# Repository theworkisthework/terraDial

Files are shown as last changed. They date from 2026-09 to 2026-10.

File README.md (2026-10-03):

# terraDial

Standalone control panel for the **terraPen** pen plotter, running on an
Elecrow CrowPanel 1.28" round display — a 240×240 touchscreen with a rotary
knob. It talks to [FluidNC](http://wiki.fluidnc.com/) over a WebSocket, so
the plotter can be driven from the bench without a laptop or phone.

Parent project: [terraForge](https://github.com/theworkisthework/terraForge)
(the desktop app this panel descends from — and the source of its colour
palette). Sibling: terraPixel (the rail lighting controller this panel can
also drive).

## What it does

- **Jog** X/Y/Z by knob, with selectable step sizes (0.1 / 1 / 10 / 100mm on
  X and Y; Z is capped at 1mm, being only a pen lift) and a per-axis *Set zero*
- **Run G-code** straight off the plotter's SD card, with live progress,
  elapsed time and an estimate of the time remaining — including for jobs
  started from terraForge or the web UI rather than the panel
- **Pen up/down**, **homing** (with a clear-the-bed confirmation), **E-Stop**
  and **alarm clear**, the last showing FluidNC's own reason for the alarm
- **Park for photo** — one dial item that lifts the pen, homes, then runs the
  gantry out to the far end of Y so the finished plot can be photographed
  unobstructed. Sequenced against the status stream rather than fired blind,
  since G-code sent mid-homing is rejected
- **Rail lighting** control via terraPixel — brightness, film mode, comet width
- **On-device Wi-Fi setup**: scan for networks, pick one, type the password
- **Machine status** shown on the panel's 5-LED ring, readable across the room
  — a jog chases a pixel the way you turned the knob, a plot breathes the
  whole ring slowly, and both dim with the screen when the panel sleeps
- **Sleep mode** so the panel isn't glowing at you through a multi-hour plot,
  with the terraPen mark shown while idle beforehand
- **About screen** carrying the project identity and QR links to the site,
  source and Discord — a 240px dial is no place to read a URL

## Screens

> These are **vector illustrations, not photographs.** They're generated by
> [`tools/gen_screens.py`](tools/gen_screens.py) from the real layout values —
> palette hex, ring radii, arc angles, hub and font sizes — so proportions and
> colours match the firmware, and icons are the same Lucide glyphs the
> firmware draws, but the panel's actual anti-aliasing isn't reproduced. A
> page taller than the round face is drawn once per screenful, scrolled.

### Main menu

The home dial and the screens it opens, in dial order.

| | | |
|:--:|:--:|:--:|
| <br>**Home** — 8 destinations, E‑Stop always red | <br>**Home XY** — clear‑the‑bed gate | <br>**Jog** — axis, position, per‑axis zero |
| <br>**Pen** — up / down | <br>**Jobs** — SD files on an open arc | <br>**E‑Stop** — feed hold + soft reset |
| <br>**Lights** — terraPixel rail control | | |

### Settings

The Settings sub‑menu, then each of its pages.

| | | |
|:--:|:--:|:--:|
| <br>**Settings sub‑menu** — Wi‑Fi, Machine, Display, About | <br>**Wi‑Fi** — network, password, connect | <br>**Wi‑Fi: network picker** — tap the SSID to scan |
| <br>**Machine: hosts** — FluidNC host / IP | <br>**Machine: pen up / down commands** — swap, reset to defaults | <br>**Machine: terraPixel** — lights host / IP |
| <br>**Display: screen** — brightness, idle logo, menu rotation | <br>**Display: sleep** — sleep timeout, ring sleep brightness | <br>**About** — identity, QR links, diagnostics |

### Pop-up screens

Not in any menu: these open by themselves when they're needed.

| | | |
|:--:|:--:|:--:|
| <br>**Radial keyboard** — opens when you tap a text field | <br>**Idle** — the mark, before sleep | <br>**Job progress** — opens when a job starts |
| <br>**Alarm clear** — appears on alarm | | |

## Hardware

| | |
|---|---|
| Board | Elecrow CrowPanel 1.28" Rotary (ESP32-S3R8, 16MB flash, 8MB PSRAM) |
| Display | GC9A01 240×240 round IPS, SPI |
| Touch | CST816D capacitive, I²C |
| Input | EC11-style rotary encoder with push switch |
| LEDs | 5× WS2812 ring around the bezel |

Pin assignments are in [`include/pins.h`](include/pins.h), confirmed against
Elecrow's factory example for this exact board rather than guessed.

### Power

It's a **USB-powered device** — a single USB-A lead carries both power and,
when you want it, the serial console and firmware flashing. There's no barrel
jack and no separate supply to find.

That also means it runs happily off a **USB battery pack**, which is handy for
a plotter that isn't parked next to a socket, or for filming without a cable
in shot. Two things worth knowing if you do:

- Many power banks cut out when they stop seeing meaningful current draw.
  This panel is a modest load to begin with, and screen sleep drops it further
  by switching the backlight off entirely — so a bank with an aggressive
  auto-shutoff may power down mid-plot. Banks with a "low-current" or
  "trickle" mode avoid this; otherwise turn sleep off (Settings → Display)
  when running from one.
- The bezel LED ring draws on the same supply, so a high ring brightness
  costs battery life directly. It's on the Lights screen if you want it down.

Enclosure files (`dial case.stl`, `frame mount.stl`, `backplate.dxf`) are in
the repo root.

## Installing and updating

Neither of these needs a toolchain, a checkout, or anything installed on the
computer. The Building section below is for changing the firmware, not for
running it.

### First install — the web installer

<https://theworkisthework.github.io/terraDial/>

Plug the panel into a computer with a USB-A **data** cable, open that page in
Chrome or Edge on the desktop, and click *Connect and install*. It talks to the
panel over Web Serial and writes the whole chip — bootloader, partition table
and app — so it also works on a board that has never been flashed, and on one
that has been flashed with something broken.

Safari, Firefox and every mobile browser lack Web Serial, so the page tells
them so rather than failing halfway.

Released builds ship with **no Wi-Fi credentials baked in** — the first boot
comes up unconnected, and you pick a network on the panel (Settings → Wi-Fi →
scan). That's the flow a stranger's board has to use anyway, so it's the one
that gets tested.

### After that — over Wi-Fi, from the panel

**Settings → About → Check for updates.**

The panel asks GitHub for the latest release, compares it against the version
it's running, and offers to install it. It downloads into the spare app slot
and reboots into it, so a failed or interrupted download leaves the working
firmware exactly where it was — there's no window where the panel is holding
half a firmware.

Two deliberate limits:

- **It refuses while the machine is busy.** The download blocks the same task
  that pumps FluidNC's WebSocket, for a minute or more, and the reboot at the
  end drops the connection outright. Mid-plot is the worst possible moment for
  both, so it says "Machine busy" and does nothing.
- **A dev build is always offered the release.** A build from a working copy
  carries the version `dev`, which has no place in the ordering — see
  `include/version.h`. If you're testing local firmware, don't press the button.

The About card shows the running version at the top, which is the thing worth
quoting in a bug report.

### Cutting a release

Tag it and push the tag; [`.github/workflows/release.yml`](.github/workflows/release.yml)
does the rest.

```bash
git tag v0.1.0
git push origin v0.1.0
```

That builds the firmware with the tag stamped in, attaches two images to the
GitHub Release, and redeploys the installer page:

| Asset | What it is |
|---|---|
| `terradial-ota.bin` | The app image. What the panel downloads for itself — the name is fixed, and `OTA_ASSET_NAME` in [`src/net/ota_updater.h`](src/net/ota_updater.h) has to keep matching it |
| `terradial-factory.bin` | Bootloader + partitions + app, merged for flashing at `0x0`. What the web installer writes |

Publishing the installer page is a second workflow,
[`pages.yml`](.github/workflows/pages.yml), which the first triggers on
success. That split isn't tidiness: the `github-pages` environment only
accepts deployments from the default branch, and a release workflow runs from
a tag — v0.1.0 failed exactly that way. A `workflow_run` trigger is evaluated
in the default branch's context whatever ref set it off, so it passes the rule
without anyone having to loosen a protection setting that lives nowhere in the
repo.

It downloads the factory image from the release it just made and serves it
from the Pages origin rather than linking to github.com — Web Serial fetches
the image with JS, and a cross-origin fetch the browser declines fails
quietly, which is a miserable thing to debug from a report that only says
"the button doesn't work".

**One-time repo setup:** Settings → Pages → Source must be set to *GitHub
Actions*, or the workflow builds everything and has nowhere to publish it.

### Test builds nobody else gets

A tag with a hyphen in it — `v0.2.0-rc1` — publishes as a GitHub
*prerelease*. It gets a release page and downloadable binaries like any
other, but no panel is offered it and the installer page ignores it: both
ask for `releases/latest`, and that endpoint skips prereleases.

That's also the only safe way to use a suffix. `versionRank()` in the
updater stops at the first non-digit, so `0.2.0-rc1` ranks *identically* to
`0.2.0` — two different builds it cannot tell apart. Keeping suffixed tags
out of `latest` means it never has to.

### Versions can only go forwards

The updater offers a release only when it ranks strictly higher than the
running build, and there is no downgrade path in the UI. So a bad release is
retired by tagging a **higher** number — never by deleting the release,
moving the tag, or re-uploading under the same one. None of those reach a
panel that has already updated.

## Building

Built with [PlatformIO](https://platformio.org/).

```bash
# 1. Build and flash
pio run -t upload

# 2. Watch the logs
pio device monitor
```

By default no credentials are compiled in: the panel boots unconfigured and
you pick a network on-device (Settings > Wi-Fi > scan). To bake in default
credentials or hostnames instead, copy `include/secrets.h.example` to
`include/secrets.h` (gitignored) and define whichever values you want to
override. They're only *defaults* either way: seeded into NVS on first boot,
after which the Settings screen can change networks without a reflash.

A local build reports its version as `dev` unless HEAD is exactly on a tag —
[`tools/version.py`](tools/version.py) only treats an exact tag as a release,
because a commit that merely descends from `v0.2.0` is newer than `v0.2.0`, and
stamping it as that version would have the updater cheerfully offer to
downgrade it.

## Using it

The knob is the primary input; touch works everywhere too.

| Gesture | Does |
|---|---|
| Rotate | Move through a ring / jog the selected axis / scroll a settings panel |
| Click | Open the highlighted item, or confirm |
| Long press | Back (out of a category first, then out of the screen) |
| Tap the centre hub | The running job, the active alarm, or E-Stop if the machine is moving — otherwise whatever the hub is naming |
| Double click | Run/delete prompt (Jobs screen only) |

**Home** is a radial dial of eight destinations, ordered the way a session
actually runs rather than by category — Home XY, Jog, Pen, Jobs, Photo,
E-Stop, Lights, Settings. The ring rests on the first of them, so the first
thing under the selection when the panel wakes is the first thing you do.
**Jobs** and **Settings** use the same ring on an open arc, which keeps the
bottom of the face clear of the back button.

Job Progress and Alarm Clear appear on their own when a job starts or an
alarm trips, and have no dial item of their own. The way back to them is the
hub: it already reports the machine state, so while that state has a screen,
tapping it opens that screen rather than the selected ring item.

That's what buys the spacing. The ring is a full circle, so every item costs
the others angle — eight sit 45° apart where ten sat 36°. E-Stop is a chip
you have to land on while something is going wrong, so it gets the room; it
also stays red at every position rather than only when selected.

Getting to E-Stop matters most where the machine is already moving under
your hand, which is not during a job — Job Progress carries its own stop
button. It's **jogging** and **homing**. So the Jog and Park screens carry a
small red stop pip beside their back button, and on the dial, tapping the
hub while the machine is homing or travelling opens E-Stop. Both open the
E-Stop screen rather than stopping outright: a stray tap near the bottom
bezel shouldn't soft-reset a machine mid-plot.

E-Stop fires on **press**, not on release, and says what it did. An
emergency jab that lands and slides off is exactly the gesture a normal
button is designed to discard, and the panel can't tell you the machine
stopped — only whether there was a connection to send the stop down. So it
answers "STOPPED" or "NOT SENT", the second meaning go and stop it by hand.

## Layout

```
.github/         release build, and the installer-page deploy that follows it
docs/screens/    README illustrations (generated)
include/         pins, palette, LVGL config, shared enums
lib/CST816D/     vendor touch driver
src/
  config/        NVS-backed settings
  display/       all UI screens and shared widgets
  input/         encoder driver
  led/           WS2812 status ring
  net/           FluidNC WebSocket client, terraPixel HTTP client, Wi-Fi
tools/           icon, logo and screen-illustration generation
web/             the browser-based firmware installer (published to Pages)
design_handoff_radial_dial_ui/   the original design brief (historical)
```

Some notes worth knowing before changing things:

- **Networking runs on core 0**, in its own task (see `networkTask` in
  `main.cpp`). mDNS lookups, WebSocket reads and HTTP calls all block for
  seconds at a time; running them in `loop()` stalls rendering and touch.
  Commands travel UI→network through a queue, and **nothing outside that task
  may touch LVGL** — LVGL is single-threaded and lives on core 1.
- **It's a round screen.** Anything more than ~120px from centre (120,120) is
  behind the bezel and physically unreachable, corners included. Several bugs
  have come from laying out against the 240×240 square instead of the circle.
- **Avoid `transform_zoom` / `lv_img_set_zoom` on anything whose parent has
  opacity < 255.** That combination pushes LVGL down an offscreen-layer path
  that is unreliable on this board — it has twice caused elements to render
  blank or vanish. Change real sizes instead.
- Colours come from [`include/palette.h`](include/palette.h), ported from
  terraForge's dark theme. Use the tokens, not literal hex.
- **The dial's order lives in three places** and they must agree:
  `DIAL_ITEMS` in `ui_dial.cpp`, the positional `switch` in `ui_nav.cpp`'s
  `onDialOpen()`, and the `screen_home()` item list in `tools/gen_screens.py`.
  Reordering one alone doesn't fail to build — it just quietly sends every
  item to the wrong screen.
- **Pace what you send FluidNC.** Commands are queued and the whole queue is
  drained in one pass, so two lines enqueued together hit the wire
  microseconds apart. `$X` immediately followed by `$H` used to alarm the
  machine on any home after the first; `home()` now unlocks only when there's
  actually an alarm and holds the `$H` until that has landed. For the same
  reason jogging is refused mid-homing — the jog-cancel realtime byte would
  stop the cycle, and FluidNC alarms on a homing cycle that didn't finish.
- Project links live in [`include/branding.h`](include/branding.h). The
  Discord URL is deliberately empty until there's a real invite — an entry
  with no URL is skipped rather than rendered as a QR that goes nowhere.
  `githubOwner()`/`githubRepo()` there are also what the updater queries, so
  a repo rename means editing them. The old **terraTouch** name still
  resolves, but only as a 301, and GitHub's API answers a redirect with a
  note about the move rather than the release — which is why the updater
  follows redirects, so a rename can't quietly kill the update path on
  panels already in the field.
- **`default_16MB.csv` is load-bearing.** The two app slots are what the OTA
  updater flashes into. A single-app partition table builds and runs perfectly
  and then fails every update at the point of no return.

## Licence

MIT — see [LICENSE](LICENSE). Same licence as its parent project
[terraForge](https://github.com/theworkisthework/terraForge).

### Third-party

The firmware image also contains third-party libraries, fonts and icons —
LVGL, LovyanGFX, ArduinoJson, arduinoWebSockets (LGPL-2.1), Adafruit NeoPixel
(LGPL-3.0), the Arduino core for ESP32 and ESP-IDF, Montserrat, Font Awesome
and [Lucide](https://lucide.dev) icons (some derived from Feather). Their
licences and copyright notices are in
[THIRD_PARTY_NOTICES.md](THIRD_PARTY_NOTICES.md), with full texts in
[`licenses/`](licenses/).

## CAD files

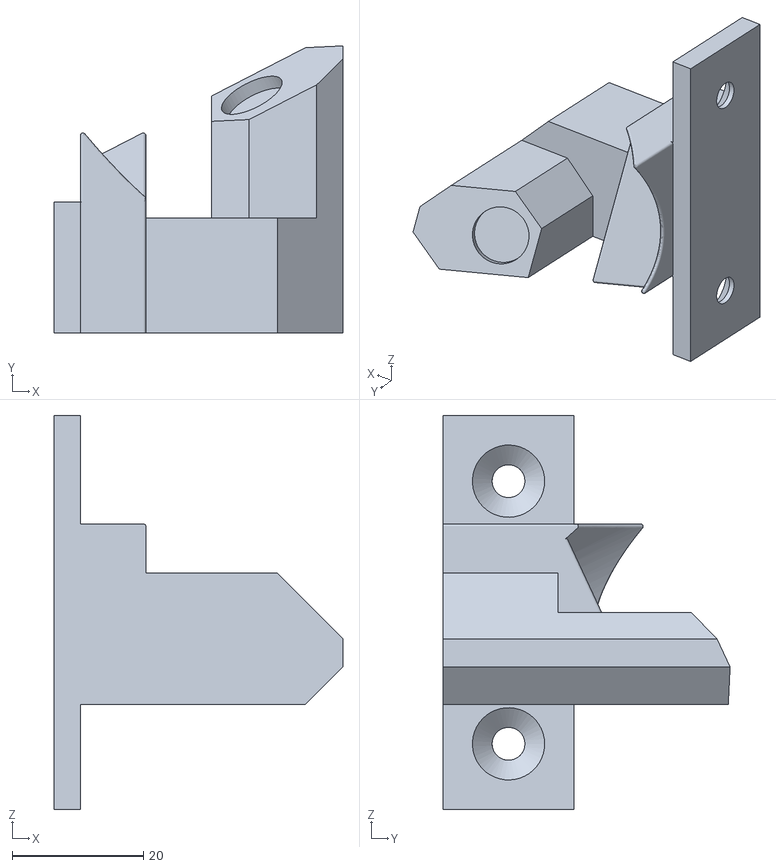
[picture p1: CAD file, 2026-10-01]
Mount Files/frame mount.stl
44.0 x 43.7 x 60.0

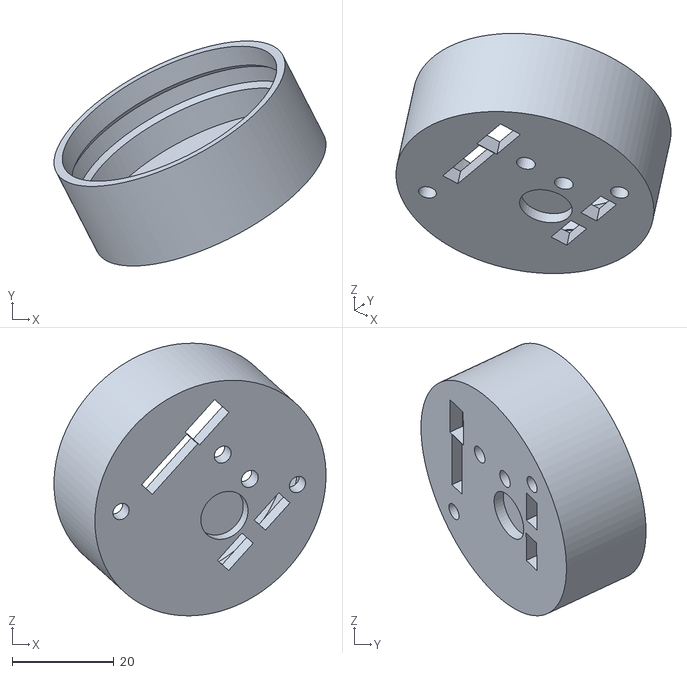
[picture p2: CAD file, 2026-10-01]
Mount Files/dial case.stl
53.3 x 44.1 x 53.5

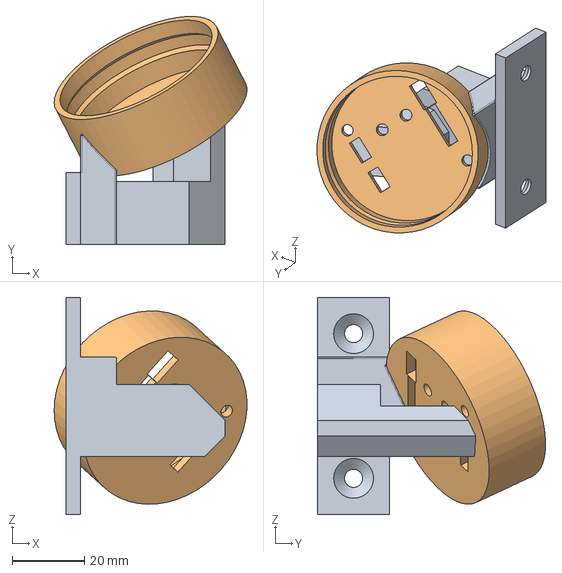
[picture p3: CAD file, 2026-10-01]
Mount Files/Dial and Mount.step
53.3 x 63.1 x 60.0 mm
rail connector
dial case

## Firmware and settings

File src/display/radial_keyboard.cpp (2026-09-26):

#include "radial_keyboard.h"
#include "palette.h"
#include <math.h>
#include <string.h>
#include <stdio.h>

namespace
{
    // ---- key model ----
    // Everything on the rim is a Key. Printable keys append their character;
    // action keys do something to the buffer or the overlay.
    enum class Action : uint8_t
    {
        Char,
        Space,
        Backspace,
        NextPage,
        Reveal,
        Accept,
        Cancel,
    };

    struct Key
    {
        const char *label; // what's drawn on the rim
        char ch;           // the character appended, for Action::Char
        Action action;
    };

    // Three pages, cycled by the "abc/ABC/123" key. Splitting them keeps any
    // one ring sparse enough that neighbouring keys don't collide visually.
    const char *PAGE_CHARS[] = {
        "abcdefghijklmnopqrstuvwxyz",
        "ABCDEFGHIJKLMNOPQRSTUVWXYZ",
        "0123456789.-_@#$%&*+=/:;,!?()",
    };
    const char *PAGE_NEXT_LABEL[] = {"ABC", "123", "abc"};
    const int PAGE_COUNT = 3;

    const int MAX_KEYS = 40;

    // How long a just-typed password character stays readable before it's
    // masked -- long enough to glance at the hub after the click, short
    // enough that it isn't sitting there for someone else to read.
    const uint32_t PEEK_MS = 3000;

    // Rim geometry on the 240px round panel (visible radius ~120). Keys sit
    // as close to the glass as an 18px glyph allows, and the hub grows out
    // to just inside them, so the whole face is keyboard rather than a
    // ring floating in empty margin.
    //
    // The selected key is centred on the same radius as the rest, NOT
    // pulled inward to make room for its bigger glyph: centring the 32px
    // label box there already puts the middle of a lowercase letter within
    // a pixel of where it sat at 18px (the bigger font's box carries more
    // descender space), and capitals still clear the glass. Pulling it in
    // made the selection visibly drop as it arrived at the top.
    const lv_coord_t RADIUS = 100;
    const lv_coord_t HUB_SIZE = 156;
    const lv_coord_t TEXT_WIDTH = HUB_SIZE - 28; // the hub is round -- leave the text clear of its curve

    // Ring motion, matched to RadialRing (the home dial, Settings, Jobs) so
    // turning the knob feels the same everywhere: the selected key sits at
    // the top and the ring springs round underneath it.
    const uint32_t SPIN_MS = 320;
    // Pushes keys near the top apart, and bunches the far side up, to give
    // the enlarged selected glyph room -- the same curve as
    // RadialRing::setSpread(), kept gentler because a far key still has to
    // be readable enough to tap. The far keys also shrink (see
    // fontForKey()), which is what leaves room to bunch them this much.
    const float SPREAD = 0.35f;
    // Keys fade with distance from the top slot, like the menu chips.
    const lv_opa_t OPA_FAR = 110;

    lv_obj_t *overlay = nullptr;
    lv_obj_t *hub = nullptr;
    lv_obj_t *titleLbl = nullptr;
    lv_obj_t *textLbl = nullptr;
    lv_obj_t *previewLbl = nullptr;
    lv_obj_t *keyLbls[MAX_KEYS] = {nullptr};
    // The font each key label currently has, so layoutKeys() only touches
    // a label's font when it crosses a size band -- a font change forces
    // the label to re-measure, which is too costly for every key on every
    // animation frame.
    const lv_font_t *keyFonts[MAX_KEYS] = {nullptr};

    Key keys[MAX_KEYS];
    int keyCount = 0;
    int selected = 0;
    int prevSelected = -1;
    int page = 0;

    // Each key's centre angle on the unrotated ring (0 = top, clockwise).
    // Keys get a share of the circle in proportion to keyWeight(), not an
    // even slice: an icon is twice a letter's width and "ABC" three times,
    // and even slices sized for letters made them overlap their neighbours.
    float keyCentreDeg[MAX_KEYS] = {0.0f};

    // Ring rotation, in hundredths of a degree. ringPos is the selection's
    // UNWRAPPED position (it keeps counting past keyCount), so the target
    // is always exactly a key's centre plus whole turns however fast the
    // knob spins, and the ring never takes the long way round when it
    // wraps. Same reasoning as RadialRing::targetOffsetX100_.
    int32_t ringPos = 0;
    int32_t ringOffsetX100 = 0;

    char buffer[80];
    size_t bufMax = sizeof(buffer) - 1;
    bool isPassword = false;
    // Password fields only: show everything typed (the rim's eye key), and
    // whether the last character is still in its PEEK_MS window.
    bool revealed = false;
    bool peekLast = false;
    lv_timer_t *peekTimer = nullptr;
    char titleText[24];

    void (*acceptCb)(const char *) = nullptr;
    void (*cancelCb)() = nullptr;

    void refreshText()
    {
        size_t n = strlen(buffer);
        if (n == 0)
        {
            lv_label_set_text(textLbl, "(empty)");
            return;
        }
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

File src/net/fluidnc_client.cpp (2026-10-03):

#include "fluidnc_client.h"
#include <WiFi.h>
#include <ESPmDNS.h>
#include <WebSocketsClient.h>
#include <HTTPClient.h>
#include <string.h>
#include "../config/settings.h"
#include "host_spec.h"
#include "demo_mode.h"

FluidNCClient fluidNC;

static WebSocketsClient wsClient;

// WebSocketsClient's onEvent wants a plain function pointer -- it has no
// notion of a bound member function, so this trampoline forwards to the
// (single) FluidNCClient instance.
static void wsEventTrampoline(WStype_t type, uint8_t *payload, size_t length)
{
    fluidNC.onWsEvent((uint8_t)type, payload, length);
}

void FluidNCClient::initTransport()
{
    if (!cmdQueue_) cmdQueue_ = xQueueCreate(CMD_QUEUE_DEPTH, sizeof(OutCmd));
    if (!fileMutex_) fileMutex_ = xSemaphoreCreateMutex();
}

void FluidNCClient::begin()
{
    // mDNS is started once in main.cpp (shared with TerraPixelClient)
    // before this is used -- nothing to do here.
}

bool FluidNCClient::enqueue(bool raw, const char *text, uint32_t ticket)
{
    if (!cmdQueue_) return false; // initTransport() not called yet -- nothing to do but drop
    if (strlen(text) > MAX_COMMAND_LEN)
    {
        // Never send a truncated command -- see MAX_COMMAND_LEN.
        Serial.printf("[fluidnc] command too long for FluidNC (%u chars), not sent: %.60s...\n",
                      (unsigned)strlen(text), text);
        return false;
    }
    OutCmd cmd;
    cmd.raw = raw;
    cmd.ticket = ticket;
    cmd.epoch = channelEpoch_;
    strcpy(cmd.text, text);
    // Never block the UI task waiting for queue space: if the network task
    // is wedged behind a slow socket, dropping a jog/status command is far
    // better than freezing the display until it recovers.
    if (xQueueSend(cmdQueue_, &cmd, 0) != pdTRUE)
    {
        Serial.printf("[fluidnc] command queue full, dropped: %s\n", text);
        return false;
    }
    return true;
}

// A queued line command from before the last newChannel(). Realtime bytes
// are never stale: '!' and 0x18 are stops, and must reach whatever is
// listening now even if they were sent a moment before a reconnect; the
// rest ('?', '~', 0x85) are harmless on any channel.
bool FluidNCClient::staleLine(const OutCmd &cmd)
{
    if (cmd.raw || cmd.epoch == channelEpoch_) return false;
    Serial.printf("[fluidnc] dropped, queued for a previous connection: %s\n", cmd.text);
    if (cmd.ticket) trackSent(cmd.ticket, false); // reads Lost
    return true;
}

void FluidNCClient::drainCommandQueue()
{
    if (!cmdQueue_) return;
    OutCmd cmd;
    while (xQueueReceive(cmdQueue_, &cmd, 0) == pdTRUE)
    {
        if (staleLine(cmd)) continue;
        if (cmd.raw) sendRaw(cmd.text);
        else
        {
            bool sent = sendLine(String(cmd.text));
            if (cmd.ticket) trackSent(cmd.ticket, sent);
        }
    }
}

// Called once a tracked line has been handed to the transport (or failed
// to be) -- after sendLine() has counted it, and before its reply can be
// read, which only happens later on this same task (or, in demo, inside
// the sim call that follows).
void FluidNCClient::trackSent(uint32_t ticket, bool sent)
{
    if (trackedPending_) publishAck(trackedTicket_, AckState::Lost); // superseded
    trackedPending_ = false;
    if (!sent)
    {
        publishAck(ticket, AckState::Lost);
        return;
    }
    trackedTicket_ = ticket;
    trackedAckIndex_ = linesSent_;
    trackedPending_ = true;
    publishAck(ticket, AckState::Pending);
}

void FluidNCClient::noteAck(bool ok)
{
    acksReceived_++;
    if (trackedPending_ && acksReceived_ == trackedAckIndex_)
    {
        trackedPending_ = false;
        publishAck(trackedTicket_, ok ? AckState::Ok : AckState::Error);
    }
}

// What's on the other end of the queue just changed: a new or dropped
// websocket, or demo mode switching over. Replies start from scratch on the
// new channel, nothing outstanding on the old one will be answered, and any
// line still queued was meant for the old one -- staleLine() drops it rather
// than run it against something else (a demo tour's pen lift reaching the
// real machine, say).
void FluidNCClient::newChannel()
{
    channelEpoch_++;
    linesSent_ = 0;
    acksReceived_ = 0;
    if (trackedPending_) publishAck(trackedTicket_, AckState::Lost);
    trackedPending_ = false;
}

uint32_t FluidNCClient::sendGcodeLineTracked(const char *line)
{
    // 30 bits, never 0. A wrap would need a billion tracked lines.
    nextTicket_ = (nextTicket_ + 1) & 0x3FFFFFFF;
    if (!nextTicket_) nextTicket_ = 1;
    return enqueue(false, line, nextTicket_) ? nextTicket_ : 0;
}

FluidNCClient::AckState FluidNCClient::ackState(uint32_t ticket) const
{
    uint32_t word = trackedAck_;
    uint32_t published = word >> 2;
    if (published == ticket) return (AckState)(word & 3);
    // Not reached the transport yet, or already superseded by a later one.
    return published < ticket ? AckState::Pending : AckState::Lost;
}

bool FluidNCClient::fileListReady() const
{
    if (!fileMutex_) return false;
    bool v = false;
    if (xSemaphoreTake(fileMutex_, pdMS_TO_TICKS(5)) == pdTRUE)
    {
        v = sdFiles_.ready();
        xSemaphoreGive(fileMutex_);
    }
    return v;
}

void FluidNCClient::clearFileListReady()
{
    if (!fileMutex_) return;
    if (xSemaphoreTake(fileMutex_, pdMS_TO_TICKS(5)) == pdTRUE)
    {
        sdFiles_.clearReady();
        xSemaphoreGive(fileMutex_);
    }
}

bool FluidNCClient::fileListFailed() const
{
    if (!fileMutex_) return false;
    bool v = false;
    if (xSemaphoreTake(fileMutex_, pdMS_TO_TICKS(5)) == pdTRUE)
    {
        v = sdFiles_.failed();
        xSemaphoreGive(fileMutex_);
    }
    return v;
}

void FluidNCClient::fileListDir(char *out, size_t outSize) const
{
    if (!outSize) return;
    out[0] = '\0';
    if (!fileMutex_) return;
    if (xSemaphoreTake(fileMutex_, pdMS_TO_TICKS(5)) == pdTRUE)
    {
        strncpy(out, sdFiles_.dir(), outSize - 1);
        out[outSize - 1] = '\0';
        xSemaphoreGive(fileMutex_);
    }
}

int FluidNCClient::fileListCount() const
{
    if (!fileMutex_) return 0;
    int n = 0;
    if (xSemaphoreTake(fileMutex_, pdMS_TO_TICKS(5)) == pdTRUE)
    {
        n = sdFiles_.count();
        xSemaphoreGive(fileMutex_);
    }
    return n;
}

bool FluidNCClient::fileListEntry(int i, FluidNCFileEntry &out) const
{
    if (!fileMutex_) return false;
    bool ok = false;
    if (xSemaphoreTake(fileMutex_, pdMS_TO_TICKS(5)) == pdTRUE)
    {
        if (i >= 0 && i < sdFiles_.count())
        {
            out = sdFiles_.entry(i);
            ok = true;
        }
        xSemaphoreGive(fileMutex_);
    }
    return ok;
}
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

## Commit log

2026-09-26 Radial keyboard fixes and wifi password entry imrpovements
    [radial_keyboard.cpp]
2026-09-26 Add clear network settings button
2026-10-01 new folder
    included step of mount and case, moved stls to folder
    [Dial and Mount.step, dial case.stl, frame mount.stl]
2026-10-03 Make pen commands mode-safe, always lift before parking, report dropped commands
    - Default pen commands now set G90 (absolute) and G21 (mm) before the
    move. The panel sends them between jobs, into whatever modes the last
    job left; G91 made pen-down a no-op and G20 made the lift five inches.
    - Park always sends the pen-up command (new uiPenLift()) instead of
    trusting the Pen screen's tracked state, which can be wrong after a
    power cycle or another client moving the pen. It stops with a reason
    if the lift can't be sent.
    - enqueue()/sendGcodeLine() now return false when a command is dropped,
    and the Pen screen only changes state once its command is queued.
    - Renders and README cache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
    [fluidnc_client.cpp, fluidnc_client.h]
2026-10-03 Wait for FluidNC to accept the pen lift before parking homes
    The pen-up command is user-editable, and one FluidNC rejects (error:N)
    leaves the machine Idle, which the park sequence's settle check couldn't
    tell from a finished lift -- so it homed with the pen down.
    - FluidNCClient counts lines sent against ok/error replies (FluidNC
    answers each line, in order, per channel), and sendGcodeLineTracked()
    returns a ticket whose reply ackState() reports: Pending, Ok, Error or
    Lost (never sent, connection dropped, demo switched, or superseded).
    Counts reset on connect, disconnect and demo enter/leave.
    - The Pen screen sends tracked; uiPenLift() returns the ticket.
    - Park waits for the lift'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
    [fluidnc_client.cpp, fluidnc_client.h]
2026-10-03 Apply pen state on FluidNC's ok; only count lines the socket accepted
    - The Pen screen keeps showing the confirmed state until the command's
    ok arrives (polled by a 50ms LVGL timer while one is outstanding).
    Error, lost, or no reply within 8s leaves it unchanged, so a rejected
    command -- or a rejected park lift -- no longer shows a pen position
    that never happened, here or on Job Progress's pen pill.
    - A new tap settles the previous reply first, so an ok already in isn't
    lost to the superseded ticket; the knob toggle flips from the state
    last asked for.
    - sendLine() returns sendTXT()'s result and only counts the line when
    the write succeeds, so a failed write can't offset reply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
    [fluidnc_client.cpp]
2026-10-03 Drop queued line commands that outlive their connection
    A command queued just before a websocket connect/drop or a demo mode
    switch was sent to whatever was on the other end afterwards -- a demo
    tour's pen lift or jog could reach the real machine, and a tracked park
    lift could be confirmed by a different backend.
    - Each queued command carries the channel epoch it was queued under;
    newChannel() (formerly resetAcks()) bumps it on connect, disconnect,
    and demo enter/leave.
    - At drain, line commands from an earlier epoch are logged and dropped,
    and a tracked one reads Lost. Realtime bytes are exempt: feed hold and
    soft reset must always get through.
    Addresses Copilot review on #19.
    Co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
    [fluidnc_client.cpp, fluidnc_client.h]
2026-10-03 Run terraPixel on its own task so it can't stall FluidNC
    terraPixel's HTTP calls block for up to 1s, and an mDNS lookup for a
    terraPixel that isn't on the network blocks for 1.5s every 3s. On
    networkTask that held up the FluidNC command queue and socket for as
    long. The lights only ran while the machine was idle, to spare jobs --
    but idle is exactly when a pen tap or the next jog is sent, so those sat
    in the queue, giving the intermittent delay when reversing a jog or
    tapping pen up/down.
    - New lightsTask (core 0, 8KB stack) runs terraPixel.update(); the
    networkTask now handles only Wi-Fi, FluidNC and OTA.
    - The "lights wait until the machine stops moving" gate is gone: it
    existed only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
    [terrapixel_client.h]
2026-10-03 Make terraPixel optional and off by default
    Most machines have no terraPixel, but the panel shipped pointed at
    terrapen-leds: a Lights item on the dial that could never work, and an
    mDNS lookup for a missing device every 3s.
    - New "Rail lights" switch under Settings > Machine > TERRAPIXEL (NVS
    tpEnabled, default off). Off, the client resets and contacts nothing,
    and the host field, status and hint are hidden.
    - Live status beside the host: Connected / Searching / Not found / Not a
    terraPixel (something answered, but not with terraPixel's /status), or
    "That's your plotter's address" when it matches the FluidNC host.
    - The dial shows Lights only while switched on (or in demo). It foll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
    [terrapixel_client.h]
2026-10-07 Add the Waveshare ESP32-S3 Knob 1.8" as a second board
    One firmware, one PlatformIO env per board. include/pins.h picks the
    board's header from include/boards/, which carries its pin map and the
    flags the rest of the code branches on (knob button, LED ring, haptics,
    battery, encoder type). The CrowPanel stays the default env.
    Waveshare Knob support:
    - ST77916 QSPI panel via LovyanGFX, with Waveshare's own init sequence
    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
2026-10-07 Draw the terraPen logo with a pen, at boot and when idle
    The identity's own animation (TP-Logo-Animated.svg) is a dot tracing the
    mark's single stroke. gen_logo.py now also writes that stroke out as a
    polyline (logo_stroke.cpp), and LogoDraw traces it at a steady, eased
    pen speed with an accent pen dot leading the line, lifting off when the
    mark is complete.
    The idle brand screen draws the mark this way instead of showing the
    bitmap, with the name and site fading in once the pen lifts. The same
    screen now runs as a boot splash that clears itself after the mark has
    held for a moment; any touch or turn skips it. It sits behind the rest
    of the top layer, so the on-screen status ring and demo t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
2026-10-07 Mirror the plot on the Job Progress screen as it's drawn
    The head's position is already reported ten times a second; whether the
    pen is down is which side of the configured pen-up/pen-down heights Z
    sits. PlotMirror records the path while a job runs and draws the
    pen-down stretches onto a canvas inside the progress ring, fitting the
    view to the drawing so far and zooming out as it grows. A dot marks the
    pen: filled on the paper, a ring when lifted.
    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
2026-10-07 Add a spirograph easter egg that the plotter can draw
    Hidden behind the logo on Settings > About: three quick taps while
    saying "terraPen" (the mic only checks that someone is talking), or
    seven quick taps on any board.
    The toy is a hypotrochoid -- a gear rolling inside a ring, the pen in a
    hole part-way out. Tap Ring, Gear or Pen and turn the knob to change
    it; the curve redraws itself with a pen dot each time. "Plot" asks for a
    size (60/100/150mm) and streams the curve to FluidNC as G-code centred
    on the pen's current position, using the pen up/down commands from
    Settings. Lines go in batches with only the last one's ok awaited, so
    the planner isn't starved between short segments. The str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
2026-10-07 Draw the logo by revealing its bitmap, not as a line
    Tracing the stroke with lv_line looked lumpy and ran at a few frames a
    second: corners snapped to whole pixels, 300-odd segments each drew
    their own round caps that overlapped at the joins, and all of them were
    redrawn every frame.
    gen_logo.py now also stores, for every pixel of iconLogo, how far along
    the stroke the pen is when it first inks it (the earliest pass where the
    stroke crosses itself). LogoDraw reveals the bitmap by that, ramping each
    pixel in over a short distance behind the pen so the edge is soft. Every
    frame is one image redraw, and the finished frame is exactly the static
    logo. The bitmaps themselves are unchanged.
    Also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
2026-10-07 Give the demo job a plot worth mirroring
    The simulated job traced a Lissajous figure six times over with a pen
    lift every second. Fine for the position readouts, but on the Job
    Progress mirror it looked like a broken drawing going round in circles.
    It now draws a fan of nine wavy arcs radiating from the bottom-right of
    the bed, one at a time, alternating direction so the pen-up hop between
    arcs is short. The pen stays up through the opening glide from wherever
    the head was, so that isn't drawn either. Four ripples per arc keeps
    them smooth at ten position reports a second.
2026-10-07 Spirograph: drag the nib, roll outside, layer copies, show the gear
    - The ring is the rim of the drawing and the gear rolls round inside
    it, outlined with an arm out to the pen, as the pattern draws; it
    parks at the start when done.
    - Drag on the drawing to put the nib under your finger: distance from
    the gear's centre sets Pen, direction sets where on the gear it sits.
    - In/Out: roll the gear round the outside of the ring instead
    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
2026-10-07 Spirograph: home before plotting, list it in Jobs, add it to the tour
    Plotting now lifts the pen, homes, then draws in machine coordinates
    (G53) 25mm clear of home on both axes -- a 100mm pattern centred at
    X75 Y75 -- using the Park macro's proven lift-then-home sequence. An
    alarm no longer blocks a plot, since homing clears it.
    The spirograph is the first entry in Jobs, at the SD root. A switch on
    Settings > About ("Spirograph in Jobs", saved) takes it out of Jobs, and
    an Open button then appears there instead, above Demo mode. The logo
    unlock still works.
    Demo mode: the simulator gets a planner queue like FluidNC's, holding a
    line's ok back while it's full, so a streamed plot runs in dem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
2026-10-07 Rename the demo job to match its drawing; show controls when paused
    The demo's snowflake.gcode now draws a fan of wavy arcs, so it's
    refraction.gcode. Same place in the list, so the tour's counts hold.
    Job Progress brings its controls up by itself while a job is held. In
    the plot-mirror view a pause otherwise looked like the drawing stalling
    for no reason -- which is what the demo tour's pause/resume step read
    as, part-way through the second arc.
    [fluidnc_client.h]
2026-10-07 Document the Waveshare Knob, plot mirror, spirograph and logo drawing
    README: both boards in the intro and hardware tables, the new features
    in "What it does", a Spirograph section, and the layout tree brought up
    to date.
    New illustrations from tools/gen_screens.py, transcribed from the
    layout code like the rest: the spirograph (inside with copies, outside,
    Plot confirm), its Jobs entry, Job Progress mirroring a plot, the logo
    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
2026-10-07 Save battery while the screen sleeps; fix the gauge after unplugging
    Battery gauge:
    - Plugging in or unplugging restarts the smoothing from the new level.
    Easing down from USB's 5V read as a full cell for the first samples
    after unplugging, then slid -- "100%, then 90% a minute later".
    - On battery the percentage only falls, unless it climbs by a clear
    margin (a load easing off), instead of ticking up and down with load.
    On battery: sleep after 60s idle unless the setting is shorter or
    "never", and the idle logo shows at 30% backlight.
    While the screen is asleep: the panel itself sleeps, the CPU drops to
    80MHz, the on-screen status ring stops animating, and the loop idles at
    20ms. Wi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
2026-10-07 Put the Waveshare Knob's second chip to sleep for good
    The Knob's other microcontroller, an ESP32, ships running Bluetooth
    audio and a Bluetooth knob, its radio up and discoverable whenever the
    board has power -- unused by terraDial and a steady battery drain.
    src/coproc/sleep.cpp is a few lines that enter deep sleep at power-on
    with no wake source. New env waveshare-knob-1_8-coproc-sleep builds it
    for that chip (esp32dev; Waveshare's own firmware runs both cores, and
    the chip reports Dual Core).
    platformio.ini: the S3 settings move from [env] into an [s3] section the
    two terraDial envs extend, so none of them leak into the ESP32 env. Both
    terraDial builds are byte-identical to before.
    RE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
2026-10-12 Wake the screen reliably: drop the CPU and panel sleep
    A sleeping dial could come back black and unresponsive until it was
    power-cycled. Low-power mode no longer changes the CPU clock at runtime
    (Arduino switches it without pausing the other core, which is mid-Wi-Fi)
    or puts the ST77916 into its own sleep. The backlight off, ring pause,
    slower loop and idle Wi-Fi power-save all stay.
2026-10-12 Spirograph: home after the plot, then run Y clear of the drawing
    Once the last line is drawn (pen up), the plot waits for Idle, homes,
    and moves Y out to 25mm past the top of the drawing, capped at the
    machine's Y travel. The progress line says Finishing... then Homing...
2026-10-12 Release and install the Waveshare Knob alongside the CrowPanel
    The Knob built and updated itself from its own asset name, but the release
    only ever built the CrowPanel, so the installer had nothing to offer a
    Knob owner and the in-dial updater always said "no update".
    - release.yml builds both envs and attaches terradial-knob18-ota.bin and
    terradial-knob18-factory.bin beside the CrowPanel's two images, which
    keep their unsuffixed names for the panels already in the field.
    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
2026-10-12 Stop the dial and terraForge kicking each other off FluidNC
    FluidNC 4.0.4+ closes older websockets in the same session when a new
    one connects, and a client with no sessionId cookie -- the dial, and
    terraForge -- lands in the shared empty session. With both running,
    each reconnect closed the other's socket, every few seconds, for as
    long as both were up. The dial now connects with ?independent_session=1,
    which gives its socket a session of its own.
2026-10-13 Address PR #22 review: spiro drain, mirror reset on disconnect, ring phase, plotting flag, sim move chaining
2026-10-13 OTA: keep displays awake, require 50% battery, warn before updating
2026-10-13 Keep Park and a spirograph plot from running over each other
    Neither checked for the other: a spirograph plot sits Idle between its
    lift, homing and batches and never sets jobActive, and Park does the same
    between its steps, so each passed the other's busy check and could send
    $H or a G53 move into the middle of the other's sequence.
    Also adds KNOWN_ISSUES.md: the rest of today's review findings, not yet
    fixed or confirmed on hardware.
2026-10-13 Spirograph: survive a pause, don't reset mid-homing, cap the points
    - A feed hold no longer counts toward the 60s no-reply timeout. A paused
    plot stops acking once the planner fills, so pausing to swap a pen for
    over a minute used to abort the plot with a soft reset. The progress
    label now says "Paused" while held.
    - Stop is hidden, and ignored, once the drawing is done and the machine is
    re-homing: a soft reset there alarms FluidNC mid-$H and loses home.
    - A plot won't start without both pen commands. A blank pen-down used to
    draw the whole thing in the air and report "Done".
    - MAX_POINTS is now a hard cap of 3000. The 12-points-a-trip floor let
    dense patterns reach about 10.7k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
2026-10-14 Fix the job-gap timers firing at once half the time
    Both used 0 for "not started" and stored millis() | 1. On an even
    millisecond that's one ms in the future, so the first check computed
    now - (now + 1), wrapped to ~4 billion, and counted the gap as long over:
    the Run/Idle blips still got through about half the time. A flag says
    whether the timer is running instead.
    Confirmed on the Knob mid-plot: the log shows one Run and one switch to
    Job Progress, then nothing, where it flicked several times a second before.
2026-10-16 Spirograph: optional homing, for plotters with no end stops
    A 'Home before plotting' setting (on by default). Off, a plot lifts the pen
    and draws in work coordinates from the user's zero, with no homing before or
    after. Refuses while alarmed, since there is no $H to clear it.
2026-10-16 Add a light/dark theme switch in Settings > Display
    Light scheme follows terraForge's :root.light tokens, with the screen
    background deepened so the light buttons stand off it. The choice is
    saved to NVS and applied at boot (the panel reboots on change), since
    colours are baked in as each screen is built.
2026-10-27 Pin the espressif32 platform to 7.1.3
    The backlight code uses the Arduino-ESP32 2.x ledc API (ledcSetup,
    ledcAttachPin). Unpinned, CI pulled a newer platform on Arduino-ESP32
    3.x, which dropped them, and the release build failed.
2026-10-27 Backlight: support the Arduino-ESP32 3.x ledc API as well as 2.x
    3.x drops ledcSetup/ledcAttachPin and addresses LEDC by pin. Choose by
    ESP_ARDUINO_VERSION_MAJOR; the 2.x path is unchanged. Only built against
    2.x so far.
